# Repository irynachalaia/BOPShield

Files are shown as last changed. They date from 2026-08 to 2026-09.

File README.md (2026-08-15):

# BOPShield

### Experimental Ball-on-Plate Platform for Control Engineering

BOPShield is an experimental educational Ball-on-Plate system developed within the **AutomationShield initiative** at the **Slovak University of Technology in Bratislava**.

The platform was developed as part of my Bachelor's thesis and is designed for education and experimentation in automatic control, mathematical modelling, and feedback control.

## Overview
The project was inspired by the well-known Ball-on-Plate mechatronic experiment, various implementations of which are publicly available. The principle of the system is based on controlling the position of a ball by changing the inclination angle of a platform along two axes. Changing the platform orientation causes the ball to move, while the control system is responsible for either stabilising the ball at a desired position or guiding it along a predefined trajectory.
<p align="center">

</p>

The main objectives of the BOPShield project were:
- Design and development of the BOPShield platform, including the selection of suitable mechanical and electronic components, electrical circuit and PCB design, system assembly, and testing of the basic functionality.
- Development and implementation of an API for Arduino IDE, enabling interaction with the BOPShield hardware and implementation of control algorithms.
- Development of a mathematical model of the system and identification of unknown system parameters.
- Design and implementation of PID and LQ/LQI controllers for system stabilisation and trajectory tracking using Arduino IDE and MATLAB/Simulink.

## Hardware and Mechanical Design

BOPShield uses a two-axis platform actuated by two servo motors, with each servo controlling the platform inclination along one of two perpendicular axes. The rotational motion of the servos is transferred to the platform through mechanical linkages, enabling independent control of its orientation along both axes. The platform is supported by a central structure connected through a universal joint. The servo arms are linked to the platform using threaded rods and ball joints, providing the required freedom of movement while maintaining mechanical stability. The platform itself consists of two main parts: a lower support for the resistive touchscreen and an upper frame that securely holds the sensor in place and prevents the ball from leaving the active surface. The entire device is designed as an Arduino-compatible add-on module. A custom printed circuit board (PCB) was developed to integrate the electronic components and provide the connections required for sensing, actuation, and overall operation of the BOPShield system.
<p align="center">

</p>

## PCB Design

The BOPShield electronics were implemented using two custom-designed printed circuit boards (PCBs).

The main PCB integrates the core electronic components of the system, including push buttons, a potentiometer, resistors, capacitors, a diode, and the electrical connections required for communication between the individual components. A two-layer PCB design was used to achieve a compact layout and efficient routing while maintaining the required connectivity between the system components.

The secondary PCB was designed as an interface between the resistive touchscreen used for ball-position sensing and the main BOPShield electronics. Since the touchscreen is equipped with an FPC cable, the interface board provides a convenient transition between the sensor and the main PCB using Molex and JST connectors. The board converts the FPC connections into individual wires that can be easily connected to the main board.
<p align="center">
pcb
</p>

 ## Control Algorithms and Trajectories

BOPShield supports several reference trajectories designed to evaluate both system stabilisation and trajectory-tracking performance:

- Center stabilisation – the controller maintains the ball near the centre of the platform, providing a basic test of system stability and disturbance rejection.

- Circular trajectory tracking – the reference position continuously follows a circular path, allowing the tracking performance of the control system to be evaluated under a smoothly changing reference.

- Elliptical trajectory tracking – the ball follows a more complex elliptical reference trajectory, providing a more demanding test of controller performance.

Two control algorithms were implemented and experimentally evaluated:

- PID controller – a classical feedback controller that determines the control action based on the error between the desired and measured ball positions.
- LQI controller – a state-feedback controller with integral action designed using the mathematical model of the system.
  
The potentiometer is used to adjust the desired speed of the ball along the selected trajectory. By changing the potentiometer position, the user can control how quickly the reference point moves along the predefined path.

 ## Experimental Results and Demonstration
 
The performance of the implemented controllers was evaluated experimentally using data collected directly from the BOPShield platform. During each experiment, the measured X and Y positions of the ball were transmitted to MATLAB/Simulink, where they were recorded and visualised for further analysis. The resulting plots show the actual motion of the ball relative to the desired reference and provide a direct comparison of the tracking performance achieved by the PID and LQI controllers. Experimental evaluation was performed for all three operating modes: centre stabilisation, circular trajectory tracking, and oval trajectory tracking.
| Trajectory | PID controller | LQ controller with integral action |
|---|---|---|
| Centre balancing | c_pid | lq_c |
| Circular trajectory | cir_PID | lq_cir|
|Oval trajectory |o_PID|lq_ov|

https://github.com/user-attachments/assets/2ce4d3ae-77bc-48d3-96e6-bf9a21eeda57

https://github.com/user-attachments/assets/c616295c-fb47-49cb-ac2f-742440809855

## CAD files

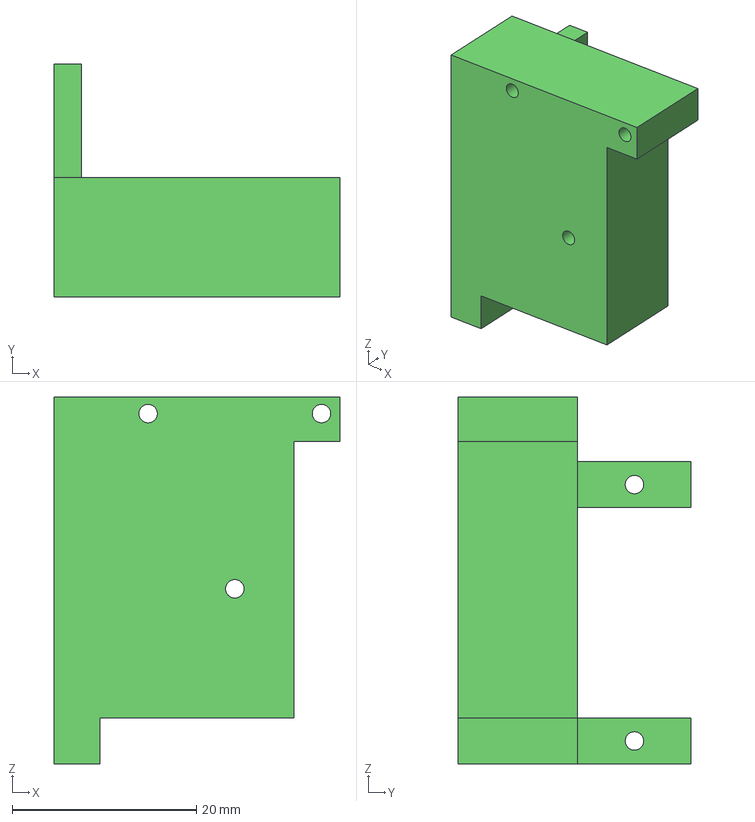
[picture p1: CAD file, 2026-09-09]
3D_models/4_2.stp
31.0 x 25.3 x 39.8 mm

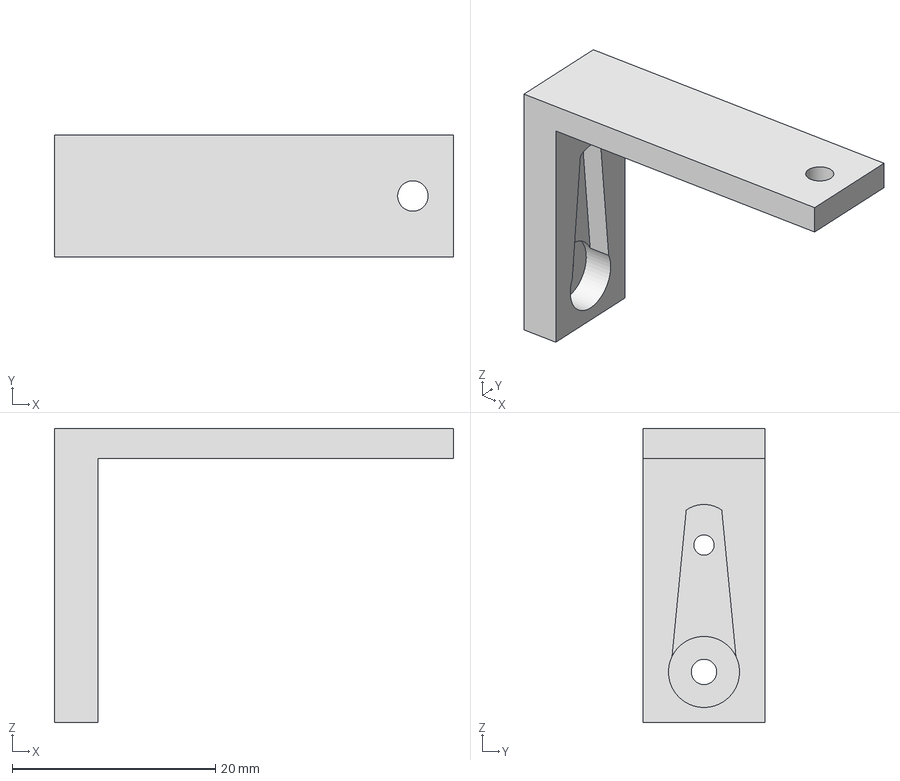
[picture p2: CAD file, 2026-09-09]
3D_models/18_1.stp
39.3 x 12.0 x 29.0 mm

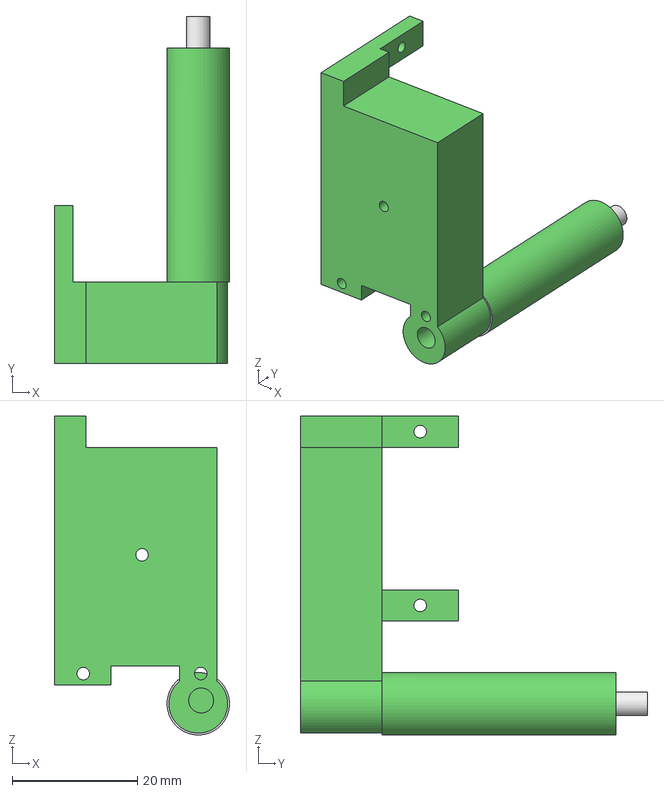
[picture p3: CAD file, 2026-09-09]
3D_models/4_1.stp
28.0 x 55.5 x 51.0 mm

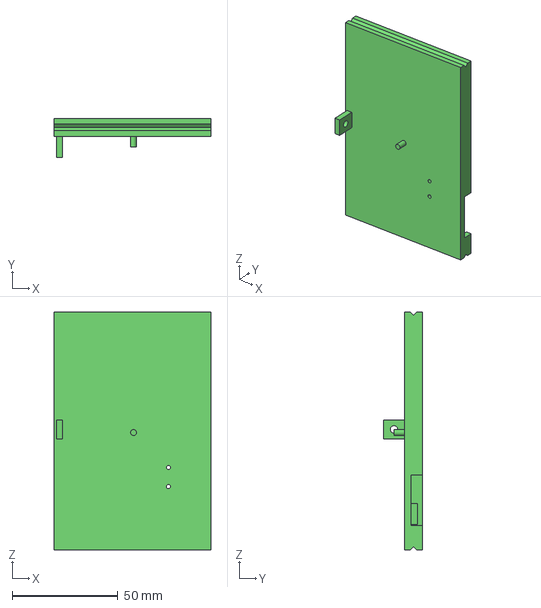
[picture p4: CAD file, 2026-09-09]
3D_models/8.stp
74.0 x 18.5 x 112.5 mm

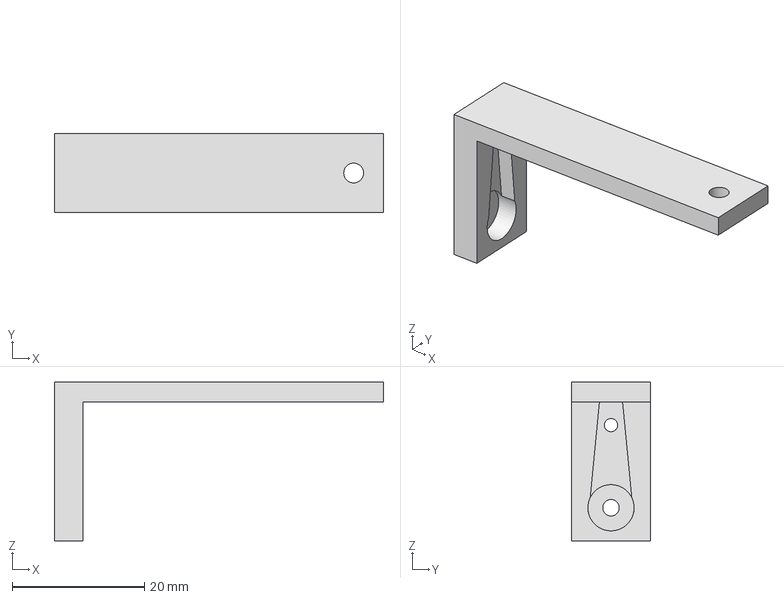
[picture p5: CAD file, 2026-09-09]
3D_models/18_2.stp
49.8 x 12.0 x 24.0 mm

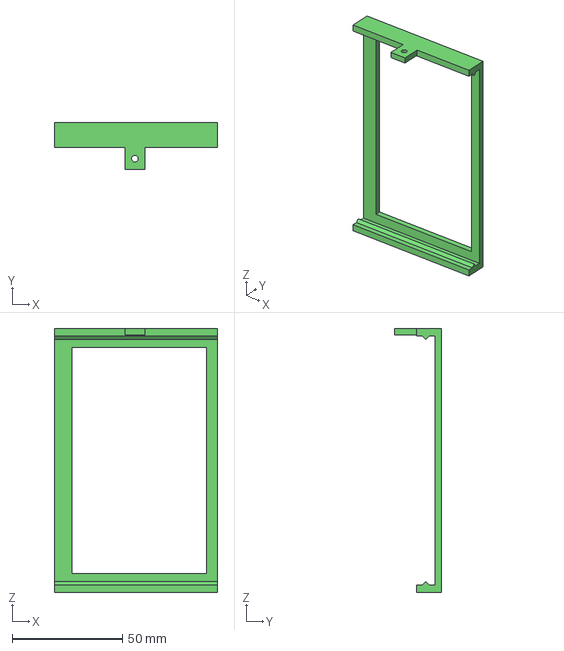
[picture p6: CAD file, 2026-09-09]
3D_models/9.stp
74.0 x 21.5 x 119.5 mm

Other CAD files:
3D_models/18_1.ipt
3D_models/18_2.ipt
3D_models/4_1.ipt
3D_models/4_2.ipt
3D_models/8.ipt
3D_models/9.ipt

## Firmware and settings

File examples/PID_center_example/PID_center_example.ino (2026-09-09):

#include <BOP_Shield.h>
#include <PIDAbs.h>

#define KP_X 0.17
#define TI_X 0.3
#define TD_X 0.8

#define KP_Y 0.17
#define TI_Y 0.4
#define TD_Y 0.6

const float Ts = 50;   // ms

float x, y;
float rX = 51.0;
float rY = 30.0;
float uX, uY;

PIDAbsClass PIDAbsX;
PIDAbsClass PIDAbsY;

void setup() {
  Serial.begin(115200);

  BOPShield.begin();
  delay(1000);
  BOPShield.calibration();

  PIDAbsX.setKp(KP_X);
  PIDAbsX.setTi(TI_X);
  PIDAbsX.setTd(TD_X);
  PIDAbsX.setTs(0.05);

  PIDAbsY.setKp(KP_Y);
  PIDAbsY.setTi(TI_Y);
  PIDAbsY.setTd(TD_Y);
  PIDAbsY.setTs(0.05);

  Serial.println("x, y, rX, rY, uX, uY, motorX, motorY");
}

void loop() {
  BLA::Matrix<2,1> XY = BOPShield.sensorRead();

  x = XY(0);
  y = XY(1);

  uX = PIDAbsX.compute(rX - x, -10, 10, -100, 100);
  uY = PIDAbsY.compute(rY - y, -10, 10, -100, 100);

  BOPShield.actuatorWrite(uX, uY);

  Serial.print(x); Serial.print(" ");
  Serial.print(y); Serial.print(" ");
  Serial.print(rX); Serial.print(", ");
  Serial.print(rY); Serial.print(", ");
  Serial.print(uX); Serial.print(", ");
  Serial.print(uY); Serial.println(" ");


  delay(Ts);
}

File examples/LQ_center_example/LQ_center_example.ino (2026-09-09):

/*
  BOPShield LQI centre point control.
*/
#include <SamplingServo.h>
#include <BOP_Shield.h>
#include <BasicLinearAlgebra.h>

using namespace BLA;

const float Ts_ms = 50.0;   // sampling period in milliseconds
const float Ts = 0.05;      // sampling period in seconds

// Reference position
float rX = 51.0;
float rY = 30.0;

// Measured position
float x = 0.0;
float y = 0.0;

// Previous measured position
float xPrev = 0.0;
float yPrev = 0.0;

// Estimated velocities from measured position
float dx = 0.0;
float dy = 0.0;

// Integral states
float intX = 0.0;
float intY = 0.0;

// Control signals
float uX = 0.0;
float uY = 0.0;

// LQI gain matrix
Matrix<2, 6> K = {
  -0.43,   -0.11,    0.0000,   -0.0000,    0.2,   -0.0000,
   -0.0000,   -0.0000,   -0.27,   -0.07,   -0.0000,    0.13
};

void setup() {
  Serial.begin(115200);
  BOPShield.begin();
  delay(1000);
  BOPShield.calibration();

  // First sensor reading for initialization
  Matrix<2, 1> XY = BOPShield.sensorRead();
  x = XY(0);
  y = XY(1);

  xPrev = x;
  yPrev = y;

  Serial.println("x, y, rX, rY, dx, dy, intX, intY, uX, uY");
}

void loop() {

  // Read measured position
  Matrix<2, 1> XY = BOPShield.sensorRead();

  x = XY(0);
  y = XY(1);

  // Calculate velocities from measured position
  dx = (x - xPrev) / Ts;
  dy = (y - yPrev) / Ts;

  // Position errors
  float eX = rX - x;
  float eY = rY - y;

  // Integral states
  intX = intX + Ts * eX;
  intY = intY + Ts * eY;

  // Anti-windup limitation
  intX = constrain(intX, -100.0, 100.0);
  intY = constrain(intY, -100.0, 100.0);

  // Augmented state vector for LQI
  Matrix<6, 1> Xa = {
    x - rX,
    dx,
    y - rY,
    dy,
    intX,
    intY
  };

  // LQI control law
  Matrix<2, 1> U = K * Xa;

  uX = U(0);
  uY = U(1);

  // Saturation of control signals
  uX = constrain(uX, -10.0, 10.0);
  uY = constrain(uY, -10.0, 10.0);

  // Send control to servos
  BOPShield.actuatorWrite(uX, uY);

  // Save previous position
  xPrev = x;
  yPrev = y;

  Serial.print(x);       Serial.print(" ");
  Serial.print(y);       Serial.print(" ");
  Serial.print(rX);      Serial.print(" ");
  Serial.print(rY);      Serial.print(", ");
  Serial.print(dx);  Serial.print(", ");
  Serial.print(dy);  Serial.print(", ");
  Serial.print(intX);    Serial.print(", ");
  Serial.print(intY);    Serial.print(", ");
  Serial.print(uX);      Serial.print(", ");
  Serial.println(uY);

  delay(Ts_ms);
}
